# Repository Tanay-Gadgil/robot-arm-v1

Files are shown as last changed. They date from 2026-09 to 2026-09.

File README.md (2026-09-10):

# 5 Axis Desktop Robot Arm
I am going to build a compact desktop 5 Axis robotic arm with around 400 mm reach and a weight of around 900g, with swappable end effectors to increase functionality.

Here is the CAD screenshot of the full arm with the claw end effector:
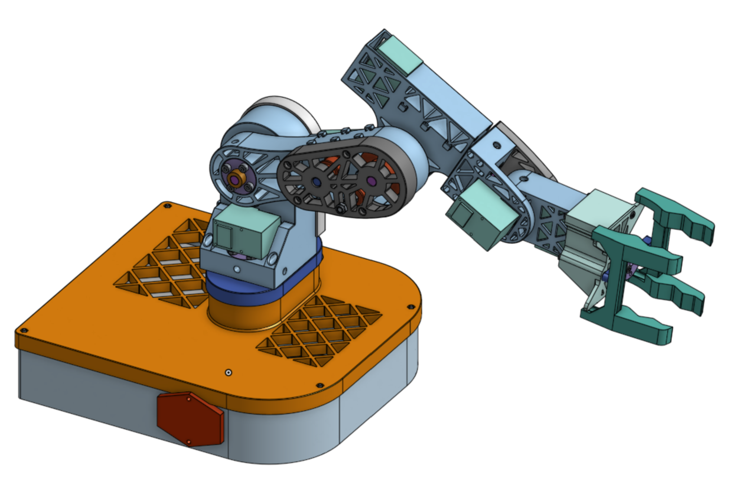
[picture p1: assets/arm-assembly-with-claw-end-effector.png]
Robot arm with claw


Here is the CAD screenshot of the drill end effector:
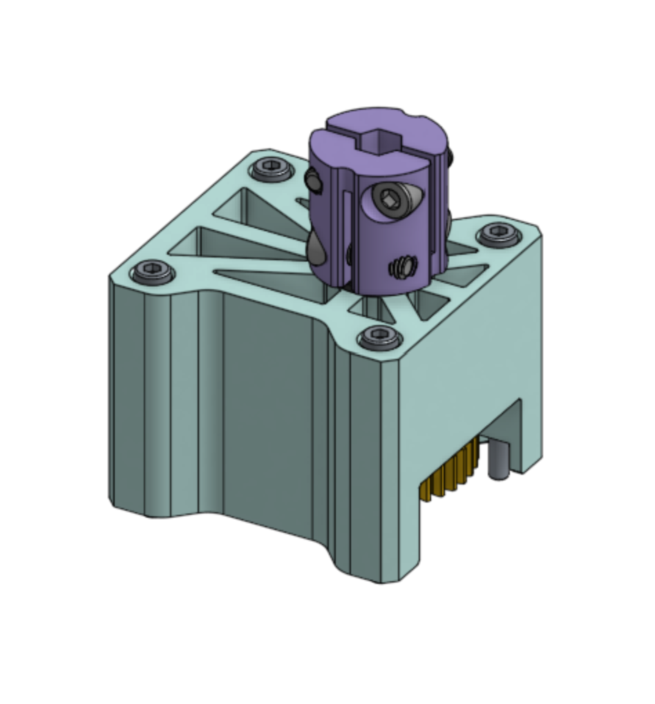
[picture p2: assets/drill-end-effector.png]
Drill end effector


All the CAD STEP files are visible in: [CAD Files](cad). Additionally, my Onshape document is available to view using the following link: [Onshape Document](https://cad.onshape.com/documents/6e9b1a5896790ac8c1d4ec04/w/12c5f12a733b298ddd2827c6/e/e15365438cc5c7eb83e6249b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)

My end goal is for the arm to be able to autonomously respond to commands using a small local AI and a router. For this, it will need to be able to take voice commands using a microphone, use a camera to navigate the environment and complete the task, talk to me in case it needs to clarify something, and run YOLO, speech to text and text to speech, and maybe a small LLM, all locally. This is why I selected the Nvidia Jetson Orin Nano Super for this project. While it is definitely overkill for V1, it will be useful in the future for these tasks. Right now I am just going to use V1 to verify that my general arm design and expected lifting capacity are where I want them to be before moving on to add computer vision and autonomous operation.

## Goals
- I want this arm to be able to perform precision movements within 1 mm accuracy and repeatability. 
- I want the arm to be able to lift at least 400 g. I am not sure if V1 can achieve this because it is a little heavy, so I will have to test it once I build it.

## Design

**Gears vs Belts:** Since gears can have backlash, I chose to use belts, since a properly tensioned belt should have minimal backlash. However, belt pulleys need to be larger to avoid putting too much strain on the belt, so they are bulkier and heavier which will affect my weight capacity.

**Torque:** I used a robot arm torque calculator to decide what ratios to use. According to the calculator, the realistic capacity for the arm at full reach is about 350g including losses from inefficiency. While this doesn't meet my goal, it is good for a first version and with belt tuning the efficiency could increase. I selected the STS3215 servos because they are affordable and adequate for most joints, and are commonly used for arms like the SO101, while I will use the higher torque STS3250 servos for joints which will see a lot of load (the 2nd and 3rd ones). In order to get enough torque at these high load joints, I am going to use a 30:60 torque multiplying ratio for the base (1st joint), a 30:80 torque multiplying ratio for the 2nd joint and a 30:60 torque multiplying ratio on the 3rd joint, with 10 mm GT2 belts which are thicker and stronger than the more common 6 mm ones. I chose to use servos because they have built in potentiometers which reduces the number of components needed for getting precise motion.

**Mass:** I tried to optimize the weight of 3d printed parts to make the arm as light as possible. However, motors and metal parts like shafts and screws make up over 75% of the actual weight so after a point it wasn't worth it to optimize the plastic parts in exchange for strength. The center of mass is around 170 mm from the L-axis pivot point (the second motor).

**Material:** I selected PETG because it can be used in most 3d printers, is similar in price to PLA, and is much less brittle than PLA. My test prints verified that it is a strong material, as it was pretty challenging to bend and it barely budged.

**Safety:** I will be using a switch and keeping all of the electronics inside of the base box to reduce risk of touching any live wires or terminals. I will also be using electrical tape to seal connections, and I have a fuse to protect the system in case of a short circuit. Here is my wiring diagram:
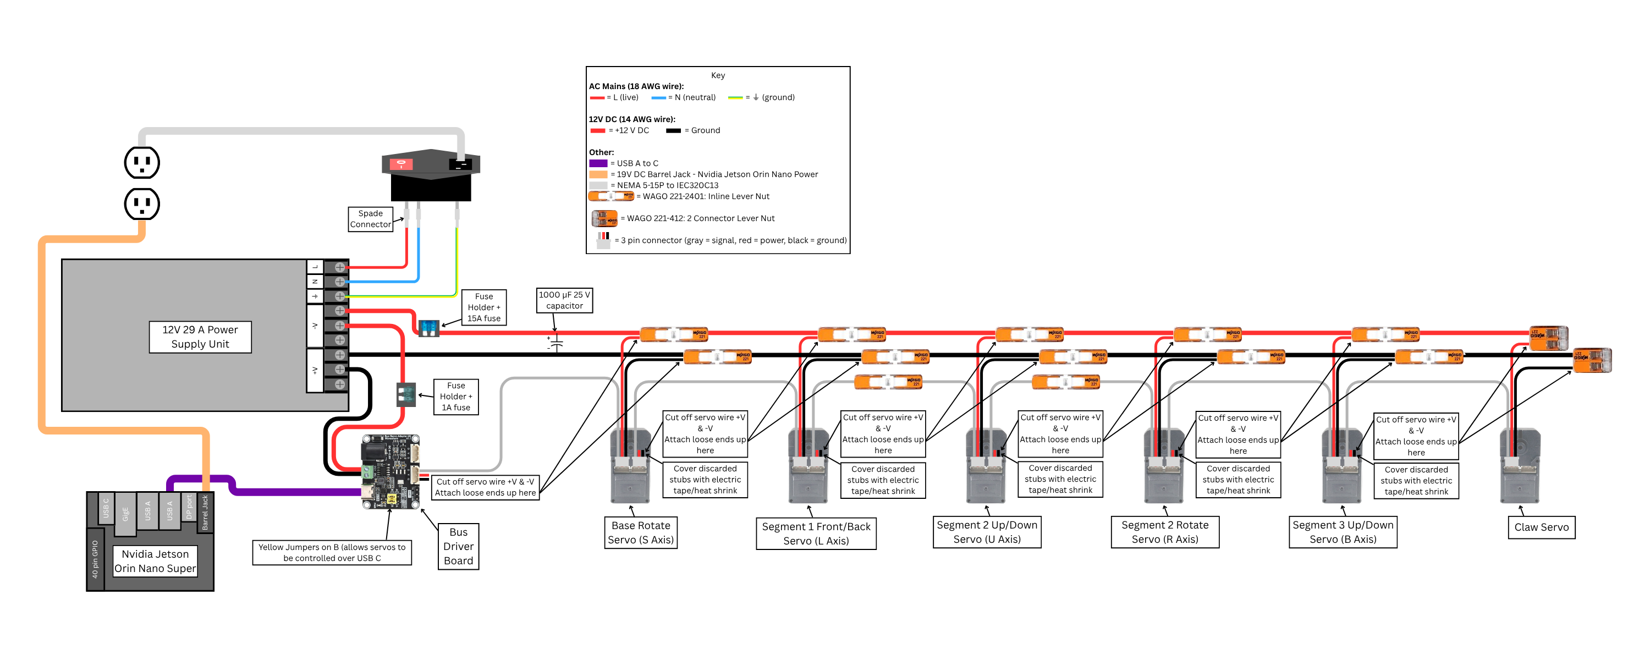
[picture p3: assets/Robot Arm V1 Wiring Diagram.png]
Wiring diagram


## Bill of Materials
My BOM is visible in BOM.csv. You can also access it from here: [BOM.csv](BOM.csv)
It shows all the parts, quantities, costs, and purchase links which are needed to assemble the arm. The BOM is split into the parts I currently need (USD $533.84 of parts) and parts I already have/have purchased (USD $636.45).

Thanks for reading!

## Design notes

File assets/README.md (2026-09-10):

Wiring diagram available, build photos coming soon.

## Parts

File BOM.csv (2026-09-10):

Part Name | Quantity | Cost Per Pack | Total Cost for All Packs | Purchase Link
GT2 8mm Bore 10 mm Belt width 30 T Pulley (6 pack) | 1 | 14.29 | 14.29 | https://www.amazon.com/uxcell-Synchronous-Aluminum-Printer-Machine/dp/B0DNFCZZ7Y?ref_=ast_sto_dp
GT2 8mm Bore 10 mm Belt width 60 T Pulley (2 pack) | 1 | 9.99 | 9.99 | https://www.amazon.com/uxcell-Synchronous-Aluminum-Printer-Machine/dp/B0DNFCY16W?ref_=ast_sto_dp
GT2 8mm Bore 10 mm Belt width 80 T Pulley (1 pack) | 1 | 11.99 | 11.99 | https://www.amazon.com/1-Pack-80T-Synchronous-Printer-Machine/dp/B0BYRQMK7J?nsdOptOutParam=true
GT2 10 mm Wide Belt 200mm Belt Loop Length (5 pack) | 1 | 8.99 | 8.99 | https://www.amazon.com/MECCANIXITY-Timing-Printing-Closed-Rubber/dp/B0GYFRRZ6B
GT2 10 mm wide Belt 232 mm belt loop length (5 pack) | 1 | 9.99 | 9.99 | https://www.amazon.com/MECCANIXITY-Timing-Printing-Closed-Rubber/dp/B0GYFXYDQT
20 T Toothless pulley for tensioning (5 pack) | 1 | 9.99 | 9.99 | https://www.amazon.com/WINSINN-Aluminum-Timing-Toothless-Printer/dp/B07BPHRSN5
8 mm ID 12 mm OD Ball bearing (12 pack) | 2 | 9.99 | 19.98 | https://www.amazon.com/uxcell-Shielded-Bearings-Electric-Skateboards/dp/B0F4XQM1NQ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
8 mm Shaft Adapter (4 pack) | 2 | 6.99 | 13.98 | https://www.amazon.com/Mrosnail-Coupling-Connector-Electroplated-Heat-Treated/dp/B0CSVZQHZY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
Waveshare Motor Driver Board (1 pack) | 1 | 12.99 | 12.99 | https://www.amazon.com/Waveshare-Integrates-Control-Applicable-Integrate/dp/B0CJ6TP3TP
12T Brass MOD 0.8 Gear for the drill end servo (1 pack) | 1 | 8.99 | 8.99 | https://www.gobilda.com/2305-series-brass-mod-0-8-servo-gear-25-tooth-spline-12-tooth/
36T Steel MOD 0.8 Gear for the drill end servo (1 pack) | 1 | 12.59 | 12.59 | https://www.gobilda.com/2303-series-steel-mod-0-8-pinion-gear-8mm-rex-bore-36-tooth/
8 mm REX Shaft (1 pack) | 2 | 4.19 | 8.38 | https://www.gobilda.com/8mm-rex-shaft-with-e-clip-stainless-steel-43mm-length/
Coupler for attaching drill bit to REX shaft (1 pack) | 1 | 9.99 | 9.99 | https://www.gobilda.com/4007-series-hyper-coupler-8mm-rex-bore-to-8mm-rex-bore/
500 mm D-shaft (1 pack) | 1 | 28.84 | 28.84 | https://www.grainger.com/product/D-Profile-Rotary-Shaft-1045-827H84
Bearing for Turntable (10 pack) | 1 | 7.89 | 7.89 | https://www.amazon.com/HiPicco-608-2RS-Bearings-Miniature-Pre-Lubricated/dp/B0CH2WZQMJ?rnid=1248859011
AC Power Inlet Switch (3 pack) | 1 | 9.59 | 9.59 | https://www.amazon.com/MKBKLLJY-Rocker-Switch-Mounting-Extension/dp/B0C2GHJGW2?sp_csd=d2lkZ2V0TmFtZT1zcF9tdGY
14 AWG Wire (10 feet each of red and black) | 1 | 9.88 | 9.88 | https://www.amazon.com/Electrical-Silicone-Flexible-Temperature-Resistance/dp/B0746H96QK
Plum Coupler for misaligned shaft (2 pack) | 1 | 11.99 | 11.99 | https://www.amazon.com/Zeberoxyz-Aluminium-Diameter20mm-Length25mm-Motor%EF%BC%888x8mm%EF%BC%89/dp/B08QVKMDC6
Rubber grommets (200 pack) | 1 | 7.99 | 7.99 | https://www.amazon.com/Firewall-Grommets-Assortment-Automotive-Organization/dp/B0F8N9PLXT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
Zip ties (1000 pack) | 1 | 7.99 | 7.99 | https://www.amazon.com/Small-Tensile-Strength-Tantti-Supply/dp/B0C2KGK2HR?sp_csd=d2lkZ2V0TmFtZT1zcF9hdGY
3/8 inch Expandable Wire Sleeving (100 ft) | 1 | 15.99 | 15.99 | https://www.amazon.com/100ft-Expandable-Braided-Sleeving-Sleeve/dp/B074GPT9Q5
PETG Filament (4x 1 kg rolls) | 1 | 42.99 | 42.99 | https://www.amazon.com/ELEGOO-Filament-Plastic-Spool-Black/dp/B0D86BXVL6
12V 29A Power Supply (1 pack) | 1 | 26 | 26 | https://www.amazon.com/LRS-350-12-Switching-Household-Industrial-Automation/dp/B07WHJF1Q8
AC power cord (1 pack) | 1 | 6.94 | 6.94 | https://www.amazon.com/Amazon-Basics-Computer-Monitor-Replacement/dp/B072BYGKZZ
WAGO 221 lever nuts (28 pack) | 1 | 20.95 | 20.95 | https://www.amazon.com/Compact-Splicing-Connector-Assortment-221-2401/dp/B0CJ5QF3VX
1000µF electrolytic capacitor, 25V (10 pack) | 1 | 6.99 | 6.99 | https://www.amazon.com/10x20mm-Electrolytic-Capacitor-Aluminum-Capacitors/dp/B0F8C1VMT6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
Bootlace Ferrules and Crimper (2000 pack) | 1 | 23.99 | 23.99 | https://www.amazon.com/Ferrule-Crimping-Connectors-Preciva-Self-adjustable/dp/B0B3N24C7Q?rnid=1248907011
Servo cables 300 mm (6 pack) | 1 | 8.99 | 8.99 | https://www.amazon.com/waveshare-5264-3PIN-Servo-Compatible-servos/dp/B0GVDPPF72
Servo Cables 300 and 900 mm mix pack (3 of each) | 1 | 9.99 | 9.99 | https://www.amazon.com/waveshare-5264-3PIN-Servo-Compatible-servos/dp/B0GVDFXF7Q
Inline fuse holder (6 pack) | 1 | 5.59 | 5.59 | https://www.amazon.com/Inline-VANTRONIK-Waterproof-Standard-standard/dp/B081YDV8PS
Multiple Sizes of Blade Fuses (80 pack) | 1 | 8.99 | 8.99 | https://www.amazon.com/gp/aw/d/B0B18NVT5Z/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
2280 NVMe SSD Gen 3 512 GB for Nvidia Jetson Orin Nano Super (1 pack) | 1 | 84.99 | 84.99 | https://www.amazon.com/Patriot-P320-512GB-Internal-SSD/dp/B0D4RCRNHG
Cat6 Ethernet Cable for Jetson Flashing and Wireless Access (1 pack) | 1 | 7.79 | 7.79 | https://www.amazon.com/Cable-Matters-Ethernet-Patch-Black/dp/B0CP9XGZKM
Rubber Tape Roll for making the claw grippy (1 pack) | 1 | 8.99 | 8.99 | https://www.amazon.com/Ealyder-Tape-Ultra-Thin-Wear-Resistant-Comfortable/dp/B0G91DVZBN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
60 foot roll of electrical tape (3 pack) | 1 | 9.96 | 9.96 | https://www.amazon.com/3M-Temflex-Electrical-1-5core-3-Roll/dp/B076D21JSP
Long PH0 Phillips screwdriver for attaching screws (1 pack) | 1 | 8.39 | 8.39 | https://www.amazon.com/uxcell-Phillips-Screwdriver-Comfortable-Handle/dp/B07D7CR5H2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
**Total Amount Needed - Funding Request** |  |  | USD $533.84
**Already Purchase/Owned - Not Part of Funding Request**
Part Name | Quantity | Cost Per Pack | Total Cost for All Packs | Purchase Link
Nvidia Jetson Orin Nano Super (1 pack) | 1 | 384.9 | 384.9 | https://www.newegg.com/nvidia-jetson-orin-nano-super-developer-kit/p/N82E16813190033
STS3215 Servo Motor (2 pack) | 2 | 48.97 | 97.94 | https://www.amazon.com/STS3215-Programmable-Magnetic-Encoder-Arduino/dp/B0FVS5HD2V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
STS3250 Servo Motor (1 pack) | 2 | 66.99 | 133.98 | https://www.amazon.com/RCmall-Feetech-STS3250-Magnetic-Encoder/dp/B0HBJLD2QG
Black and Decker Drill Bits set | 1 | N/A | N/A | N/A - not sure where it was purchased from
Hex Socket Screw - Full/Partial Thread, Standard Type (DIN 912/GB/T 70.1) (M3 x 6 mm) | 20 | 0.0063 | 0.13 | https://jlcmc.com/product/s/E02/EDLA/din-912-gb-t-70.1-standard-socket-head-cap-screws-full---half-thread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
Hex Socket Screw - Full/Partial Thread, Standard Type (DIN 912/GB/T 70.1) (M3 x 10 mm) | 20 | 0.0075 | 0.15 | https://jlcmc.com/product/s/E02/EDLA/din-912-gb-t-70.1-standard-socket-head-cap-screws-full---half-thread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
Hex Socket Screw - Full/Partial Thread, Standard Type (DIN 912/GB/T 70.1) (M3 x 20 mm) | 20 | 0.0119 | 0.24 | https://jlcmc.com/product/s/E02/EDLA/din-912-gb-t-70.1-standard-socket-head-cap-screws-full---half-thread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
Hex Socket Screw - Full/Partial Thread, Standard Type (DIN 912/GB/T 70.1) (M3 x 25 mm) | 20 | 0.0145 | 0.29 | https://jlcmc.com/product/s/E02/EDLA/din-912-gb-t-70.1-standard-socket-head-cap-screws-full---half-thread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
Hex Socket Screw - Full/Partial Thread, Standard Type (DIN 912/GB/T 70.1) (M3 x 35 mm) | 20 | 0.0189 | 0.38 | https://jlcmc.com/product/s/E02/EDLA/din-912-gb-t-70.1-standard-socket-head-cap-screws-full---half-thread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
Hex Socket Screw - Full/Partial Thread, Standard Type (DIN 912/GB/T 70.1) (M3 x 40 mm) | 20 | 0.021 | 0.42 | https://jlcmc.com/product/s/E02/EDLA/din-912-gb-t-70.1-standard-socket-head-cap-screws-full---half-thread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
Hex Socket Screw - Full/Partial Thread, Standard Type (DIN 912/GB/T 70.1) (M4 x 12 mm) | 20 | 0.0141 | 0.28 | https://jlcmc.com/product/s/E02/EDLA/din-912-gb-t-70.1-standard-socket-head-cap-screws-full---half-thread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
Hex Socket Screw - Full/Partial Thread, Standard Type (DIN 912/GB/T 70.1) (M4 x 20 mm) | 20 | 0.0181 | 0.36 | https://jlcmc.com/product/s/E02/EDLA/din-912-gb-t-70.1-standard-socket-head-cap-screws-full---half-thread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
Hex Socket Screw - Full/Partial Thread, Standard Type (DIN 912/GB/T 70.1) (M4 x 25 mm) | 20 | 0.0204 | 0.41 | https://jlcmc.com/product/s/E02/EDLA/din-912-gb-t-70.1-standard-socket-head-cap-screws-full---half-thread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
Hex Socket Screw - Full/Partial Thread, Standard Type (DIN 912/GB/T 70.1) (M5 x 40 mm) | 10 | 0.043 | 0.43 | https://jlcmc.com/product/s/E02/EDLA/din-912-gb-t-70.1-standard-socket-head-cap-screws-full---half-thread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
Hex Socket Screw - Full/Partial Thread, Standard Type (DIN 912/GB/T 70.1) (M5 x 45 mm) | 10 | 0.0445 | 0.45 | https://jlcmc.com/product/s/E02/EDLA/din-912-gb-t-70.1-standard-socket-head-cap-screws-full---half-thread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
Flat Washer Level A (3 mm ID) | 200 | 0.0016 | 0.32 | https://jlcmc.com/product/s/E06/EPDA/flat-washer-level-a?k=EPDA-S1W-B-5&productModelNumber=EPDA-S1W-B-3
Flat Washer Level A (4 mm ID) | 50 | 0.0023 | 0.12 | https://jlcmc.com/product/s/E06/EPDA/flat-washer-level-a?k=EPDA-S1W-B-4&productModelNumber=EPDA-S1W-B-4
Flat Washer Level A (5 mm ID) | 50 | 0.0029 | 0.15 | https://jlcmc.com/product/s/E06/EPDA/flat-washer-level-a?k=EPDA-S1W-B-5&productModelNumber=EPDA-S1W-B-5
Flat Washer Level A (8 mm ID) | 50 | 0.0088 | 0.44 | https://jlcmc.com/product/s/E06/EPDA/flat-washer-level-a?k=EPDA-S1W-B-8&productModelNumber=EPDA-S1W-B-8
Locking ring Set screw locking Compact (8 mm ID) | 5 | 1.37 | 6.83 | https://jlcmc.com/product/s/F07/FGDB/locking-ring-set-screw-locking-compact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
Anti-loosening nut (M3) | 300 | 0.0074 | 2.01 | https://jlcmc.com/product/s/E04/EMLC/anti-loosening-nut?k=EMLC-S1-N-M3&productModelNumber=EMLC-S1-N-M3
Anti-loosening nut (M4) | 300 | 0.0097 | 2.64 | https://jlcmc.com/product/s/E04/EMLC/anti-loosening-nut?k=EMLC-S1-N-M4&productModelNumber=EMLC-S1-N-M4
Anti-loosening nut (M5) | 300 | 0.0102 | 2.79 | https://jlcmc.com/product/s/E04/EMLC/anti-loosening-nut?k=EMLC-S1-N-M5&productModelNumber=EMLC-S1-N-M5
Internal Retaining rings (EQDE) C Type (12 mm) | 50 | 0.0157 | 0.79 | https://jlcmc.com/product/s/E05/EQDE/internal-retaining-rings-(eqde)-c-type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
Total |  |  | USD $636.45
Grand Total |  |  | USD $1170.29

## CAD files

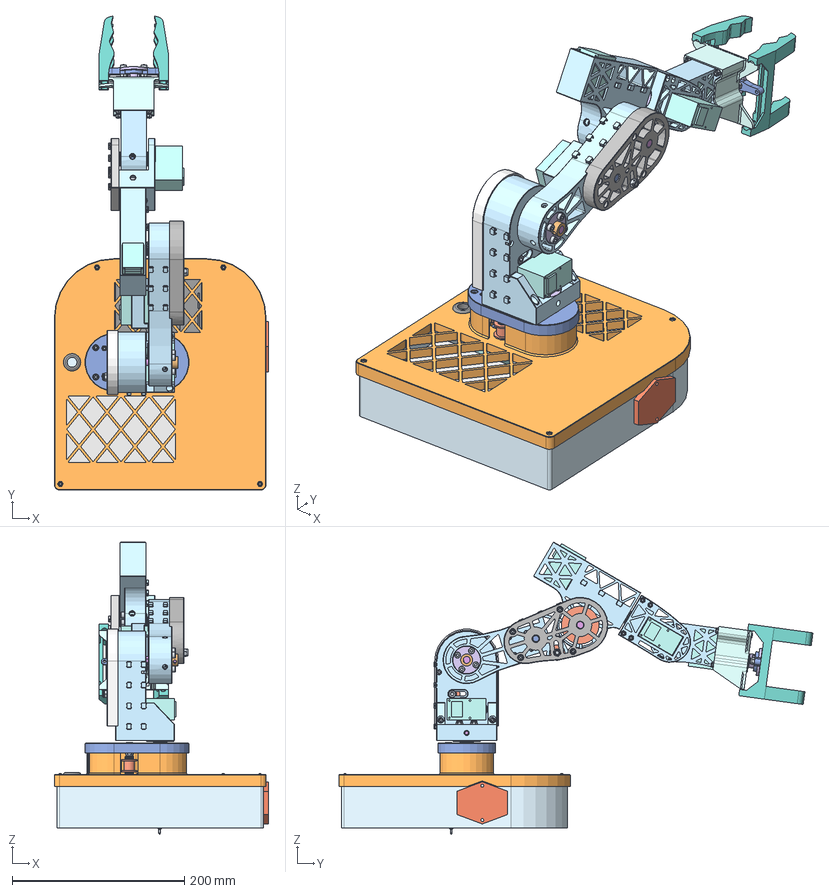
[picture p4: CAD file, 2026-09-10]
cad/arm-assembly-with-claw-end-effector.step
249.0 x 550.8 x 340.0 mm
Cross recessed pan head tapping screw ST2.2x6.5 x 23
Prevailing torque thin nut grade A M5x0.8 x 8
Hex socket head cap screw M4x0.70 x 20 x 12
Prevailing torque thin nut grade A M3x0.5 x 29
Hex socket head cap screw M4x0.70 x 25 x 8
8mm Washer x 16
Ball Bearing x 11
Prevailing torque thin nut grade A M4x0.7 x 18
D-Shaft Joint 1
Motor x 4
Hex socket head cap screw M3x0.50 x 40 x 18 x 19
Adapter Base
Motor Box Lid
5mm Washer x 12
20 Toothless Pulley x 3
Arm Segment 4 V3
Claw 2nd Side
Hex socket head cap screw M3x0.50 x 5 x 12
Hex socket head cap screw M5x0.80 x 45 x 2
Actuating Arm
D-Shaft Adapter x 6
Hex socket head cap screw M3x0.50 x 35 x 18 x 4
Hex socket head cap screw M4x0.70 x 12 x 2
60 T Pulley x 2
8 x 43 mm REX Shaft
Motor Bare (No Spline Adapter) x 2
80 T Pulley
D-Shaft Joint 2 x 2
End Effector Claw V2
Adapter Joint 1
36 T REX gear
Hex socket head cap screw M5x0.80 x 40
Claw 1st Side
Arm Segment 1 Lid
Adapter Joint 3
Bearing Spacer 2
Servo Shaft (Cut)
Arm Segment 2 V5
Plum Coupler Simple
Motor Box
30 T Pulley x 3
Bearing Spacer
P1 Arm Segment 3 V4
P2 Arm Segment 3 V4 Copy 2
Arm Segment 1
Shaft Collar
12 T Gear
Servo Bus Driver
Big Bearing x 3
Lid for Lid
Hex socket head cap screw M3x0.50 x 10 x 6
Power Supply
5/8 in Rubber Grommet
Adapter Base Pivot
Bearing Retainer 2
Base
AC Power Inlet Module
D-Shaft Base
Jetson Orin Nano Super
Base Lid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

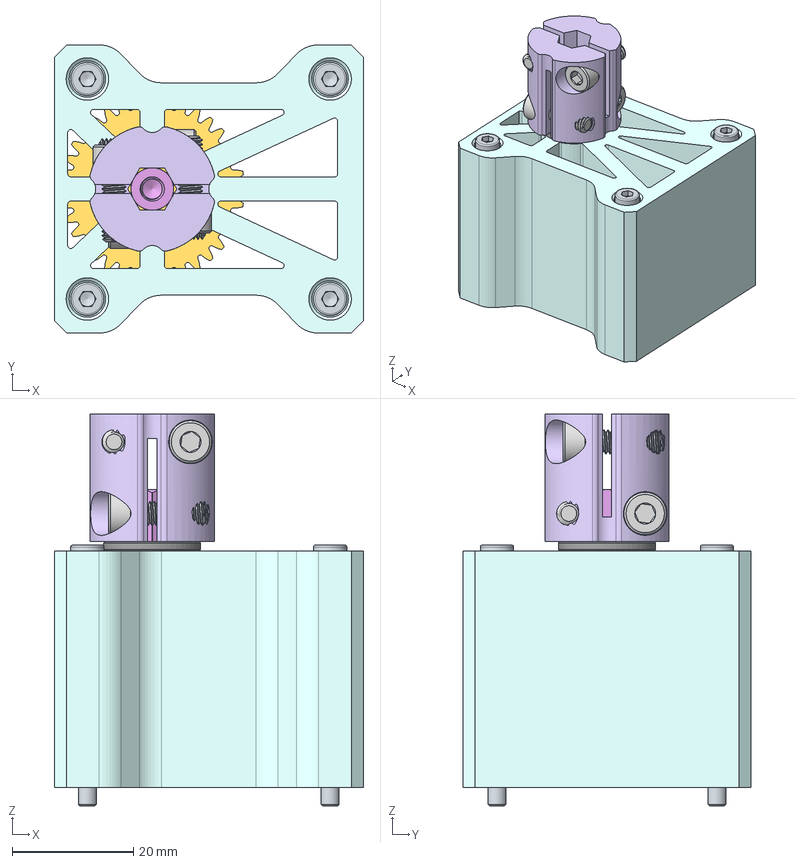
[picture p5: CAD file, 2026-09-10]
cad/drill-end-effector.step
50.9 x 47.5 x 64.6 mm
36 T REX gear
Ball Bearing x 2
Screw 1 x 4
8 x 43 mm REX Shaft
8mm Washer x 2
Hex socket head cap screw M3x0.50 x 40 x 18 x 4
REX Adapter
Bearing Spacer
End Effector Drill V2

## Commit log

2026-09-09 Add initial README for servo control code
2026-09-09 Add initial folder and README for CAD files
2026-09-10 Added Wiring Diagram PNG to assets
2026-09-10 Added arm and end effector files to cad folder
    [Claw Assembly.step, Drill End Effector.step]
2026-09-10 Added new, updated CAD files
    [arm-assembly-with-claw-end-effector.step, drill-end-effector.step]
2026-09-10 Add images of CAD
    Add images of both the drill end effector and arm with the claw end effector attached.
2026-09-10 README first draft for 5 Axis Desktop Robot Arm project
2026-09-10 Update README.md for cad
